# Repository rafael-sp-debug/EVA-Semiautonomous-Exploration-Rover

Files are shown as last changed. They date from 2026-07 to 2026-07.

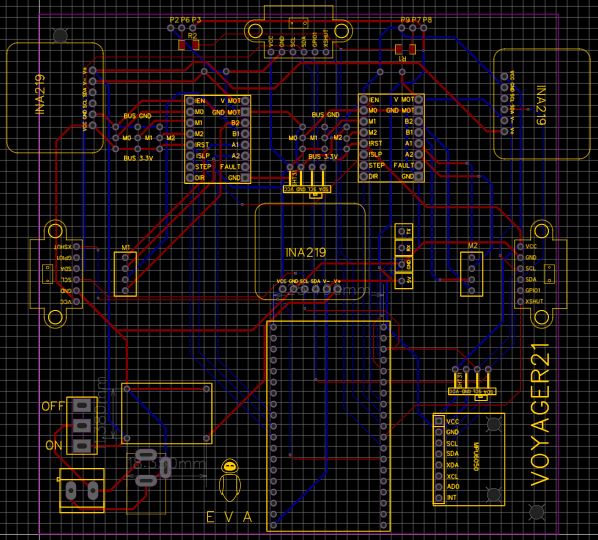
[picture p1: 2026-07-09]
Hardware/PCBs/ROVER_EVA.JPG

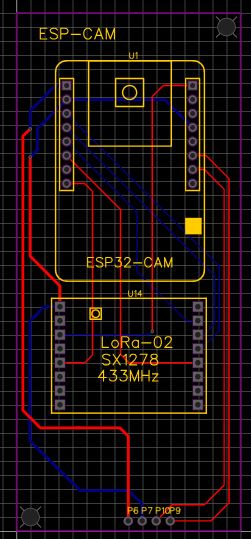
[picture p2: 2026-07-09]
Hardware/PCBs/CAM_EVA.JPG

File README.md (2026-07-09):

# EVA-Rover_2025 — Autonomous Exploration and Manual Control with LoRa

A complete hardware and software system that controls the differential rover **EVA** through an exploration cycle: autonomous navigation with obstacle avoidance, manual control, real-time telemetry transmission, and image capture. All operated from a remote ground station via long-range links.

The rover integrates sensor fusion for health monitoring (IMU, ToF, Voltage/Current), an **A*** path planner for grid navigation, and a **Computer Vision (YOLOv8 and OpenCV)** system at the base station for object and color detection. The entire system is orchestrated by an adaptive dynamic communication protocol over **LoRa**.

> Developed for the Space Technologies concentration at Tecnológico de Monterrey. 








---

## Demo

https://github.com/user-attachments/assets/1a435b37-e4af-4b8c-88f6-09a919b76a1f

| | |
|---|---|
| **Mission** | Explore the terrain manually or autonomously, avoid obstacles, capture images, and send real-time telemetry. |
| **Mechanical Design** | Modular PLA chassis < 20x20 cm, TPU tires for high traction, NEMA17 actuators. |
| **Sensors** | MPU6050 (IMU), VL53L0X x3 (ToF Distance), INA219 (Power), SHT31/AHT10 (Temp/Hum). |
| **Navigation** | A* Planner (Manhattan Heuristic) with reactive Evasion and Escape modes. |
| **Communications** | LoRa link (433MHz) with dynamic adaptation of SF and Bandwidth (Short/Mid/Long range). |
| **Computer Vision** | Base64 capture via ESP32-CAM; YOLOv8 (Faces/Rovers) and OpenCV (Colors) detection at the ground base. |

---

## How it Works

The system is divided into independent subsystems running on three main microcontrollers: an ESP32 and an ESP32-CAM on the rover, and an ESP32 at the ground station.

```text
                  [ ESP32-CAM (Payload) ]
                             │ Base64 Image Chunks
                             ▼
 ┌─────────────────────────────────────────────────────┐      LoRa (433MHz)       ┌───────────────────────┐
 │                      EVA ROVER                      │ ◄── (Commands / ACKs) ──►│    GROUND STATION     │
 │                                                     │ ◄───── (Telemetry) ─────►│                       │
 │  [ ESP32U Central ]                                 │                          │  [ ESP32U ]           │
 │     ├─ Navigation (MotorTask, A*)                   │                          │      │ (UART-USB)     │
 │     ├─ Telemetry (I2C: IMU, ToF, INA219, SHT31)     │                          │      ▼                │
 │     └─ Actuators (DRV8825 -> NEMA17)                │                          │  [ Computer (PC) ]    │
 └─────────────────────────────────────────────────────┘                          │  Web UI (WebSockets)  │
                                                                                  │  Digital Twin         │
                                                                                  │  Vision (YOLO/OpenCV) │
                                                                                  └───────────────────────┘
```
---
## Subsystems (Modules)

| Subsystem | Description | Key Components |
|---|---|---|
| **Communications** | Pseudo-full duplex bidirectional link. Dynamically adapts its Spreading Factor (SF7 to SF11) based on average RSSI to secure the link. | Ra-02 Modules (LoRa 433MHz), UART |
| **Sensors** | Collects 24 scaled sensory variables in a 65-byte CSV packet sent to the base. Manages visual rover states via a Neopixel matrix. | MPU6050, VL53L0X, INA219, AHT10 |
| **Navigation** | Discretizes the environment into 33 cm cells. Uses A* to plan routes towards targets (`GOAL X Y`). If a ToF sensor detects a blockage, it triggers bypass (evasion) or 180° turn (escape) modes. | ESP32U, DRV8825, NEMA17 |
| **Payload (Capture)** | Captures images, encodes them in Base64, and splits them into chunks (e.g., 64-200 bytes). Sends them with integrity checks, re-requesting lost parts. | ESP32-CAM, OV2640 Camera |
| **Ground Station** | Generates a WiFi Access Point. Deploys a Web Dashboard (HTML/JS/CSS) that graphs telemetry, draws the obstacle map, and sends commands via WebSockets. | Embedded Web Server, Python |

---

## Commands and Control

The system processes the following commands sent from the serial interface or the web dashboard to the rover:

| Command | Action | Command | Action |
|---|---|---|---|
| `W`, `S` | Move Forward / Backward one cell | `AUTO` / `STOPAUTO` | Starts / Stops autonomous navigation mode |
| `A`, `D` | Turn 90° Left / Right | `GOAL X Y` | Sets a target at X, Y coordinates |
| `IMAGE` | Capture and request an image | `REVERSE` | Returns the rover to the origin (0,0) |
| `START` / `STOP` | Start / Stop telemetry flow | `OBJ X Y` | Manually defines a logical obstacle on the map |
| `FORCE###` | Forces LoRa mode (`SHORT`, `MID`, `LONG`) | `CLEARALL` | Resets the map and robot position |

---

## Technical Approach

*   **Dynamic LoRa Adaptation:** To prevent packet loss over long distances, the station evaluates the average RSSI. If it drops below specific thresholds (-65 dBm, -95 dBm), the system automatically negotiates a mode change (increasing the Spreading Factor from SF7 to SF9 or SF11 and the preamble), sacrificing speed for robustness.
*   **Secure Image Transmission:** Since LoRa easily loses packets, images are encoded in Base64 and sent in small "Chunks". The station requests the pieces one by one, verifying their length and ASCII content. If a timeout or error occurs, it specifically re-requests that chunk.
*   **Safe Navigation:** All movement relies on a central non-blocking task (`motorTask()`). This prevents race conditions between telemetry and motor control, ensuring that odometry pose updates remain accurate.
*   **Digital Twin & Vision:** The project features a digital twin in Webots that replicates the real robot's movements in 3D using received telemetry. Additionally, images arriving at the PC go through YOLOv8 (trained on 10,000 augmented images) to detect faces and rovers, and OpenCV for color segmentation (Red, Blue, Green, Yellow).

---

## Installation and Materials

To replicate this project, you need to manufacture the custom PCBs and assemble the 3D design.

**Main Materials:**
*   4x 18650 Li-ion Batteries and MP1584 Regulator
*   2x NEMA17 Motors with DRV8825 drivers
*   2x ESP32-DevKitC-32U and 1x ESP32-CAM
*   2x Ra-02 LoRa Modules (433MHz)
*   PLA (Chassis) and TPU (Tires) filaments

*(All technical information, STL files, and detailed BOM can be found in the `/Hardware` folder of the repository).*

---

## Authors

*   Rafael Soto Padilla
*   José Eduardo Castellanos Avila
*   Nicolas De Bruijn Prieto
*   Diana Marisol Hernández Jiménez

## References

1. **Macenski, S., Foote, T., Gerkey, B., et al.** (2022). *Robot Operating System 2: Design, architecture, and uses in the wild*. Science Robotics, 7(66). [https://docs.ros.org/en/humble/](https://docs.ros.org/en/humble/)
2. **Jocher, G., Chaurasia, A., & Qiu, J.** (2023). *Ultralytics YOLOv8* (Version 8.0.0) [Computer software]. [https://github.com/ultralytics/ultralytics](https://github.com/ultralytics/ultralytics)
3. **Hart, P. E., Nilsson, N. J., & Raphael, B.** (1968). *A Formal Basis for the Heuristic Determination of Minimum Cost Paths*. IEEE Transactions on Systems Science and Cybernetics, 4(2), 100-107.
4. **Espressif Systems.** (2023). *ESP32 Series Datasheet*. [https://www.espressif.com/sites/default/files/documentation/esp32_datasheet_en.pdf](https://www.espressif.com/sites/default/files/documentation/esp32_datasheet_en.pdf)
5. **Semtech Corporation.** (2020). *LoRa Modulation Basics* (AN1200.22). [https://semtech.my.salesforce.com/sfc/p/E0000000JelG/a/2R0000001Rbr/6EfVZUorrpoKFfvaF_Fkpgp5kzjiNyiAbqcpqh9qSjE](https://semtech.my.salesforce.com/sfc/p/E0000000JelG/a/2R0000001Rbr/6EfVZUorrpoKFfvaF_Fkpgp5kzjiNyiAbqcpqh9qSjE)
6. **Bradski, G.** (2000). *The OpenCV Library*. Dr. Dobb's Journal of Software Tools. [https://opencv.org/](https://opencv.org/)

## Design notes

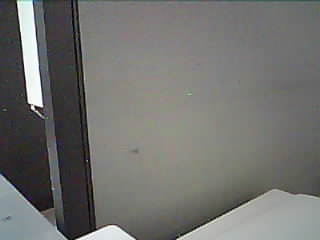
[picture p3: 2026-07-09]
Documentación/Evaluaciones/Cetec - CEDES.jpeg

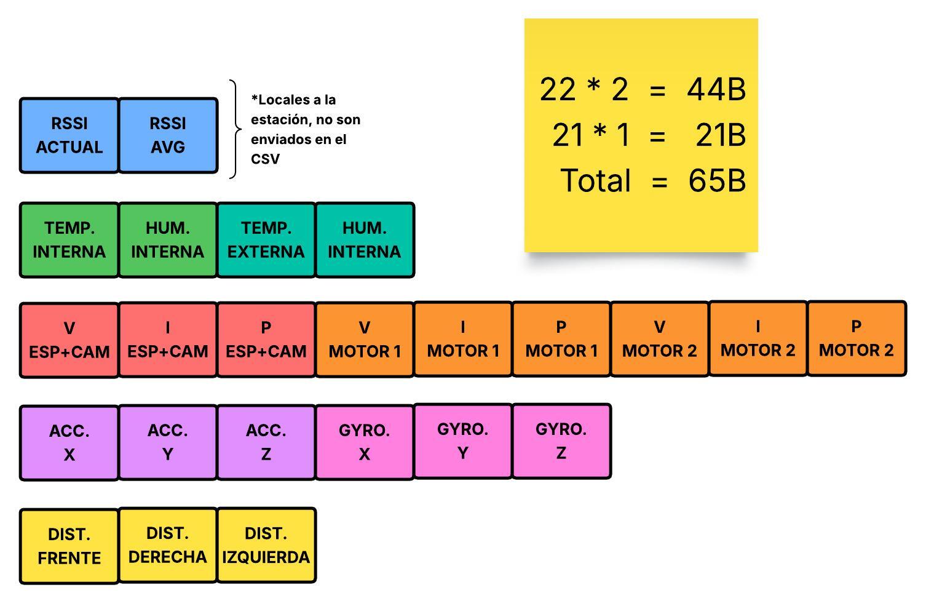
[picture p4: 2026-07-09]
Documentación/Diagramas/Estructura CSV.jpeg

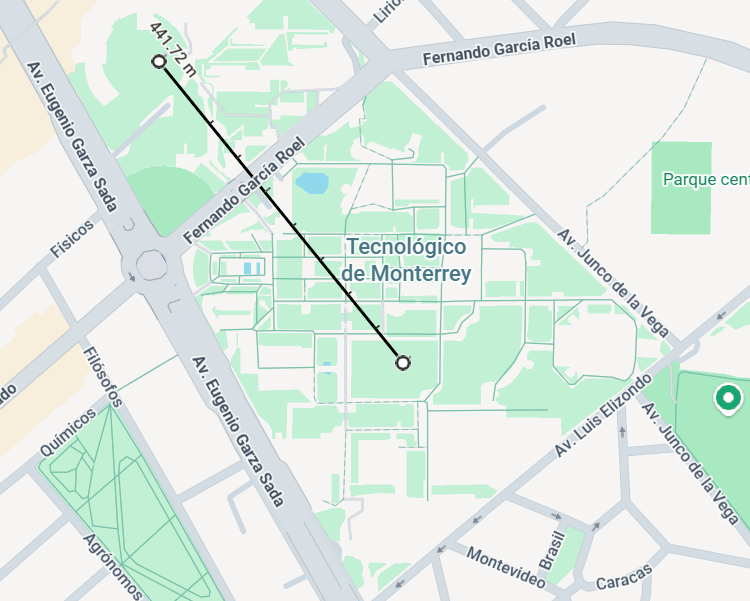
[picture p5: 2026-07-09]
Documentación/Evaluaciones/Distancia_BIBLIO - CEDES.png

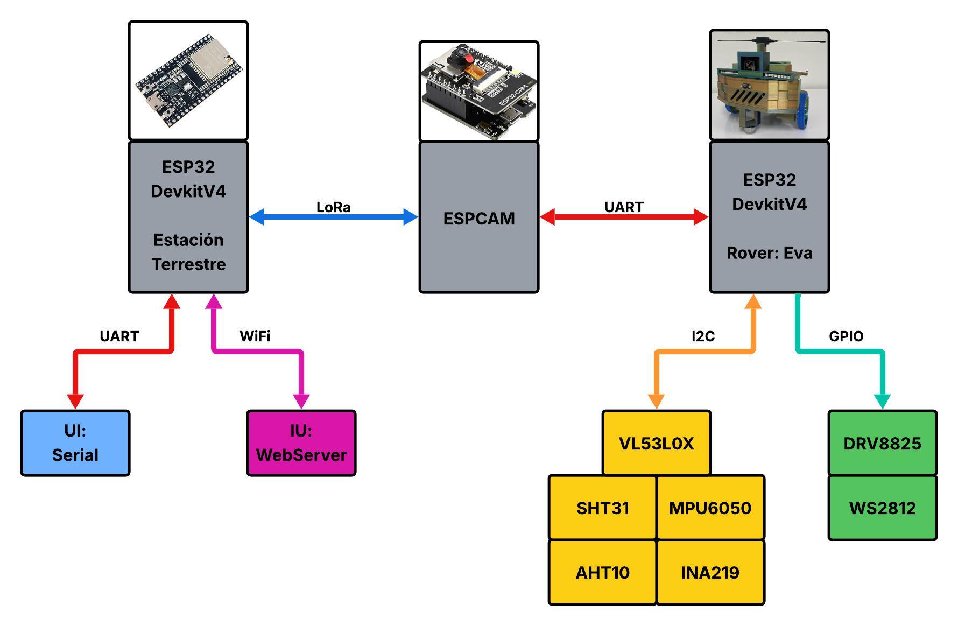
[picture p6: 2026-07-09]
Documentación/Diagramas/Protocolos Empleados.jpeg

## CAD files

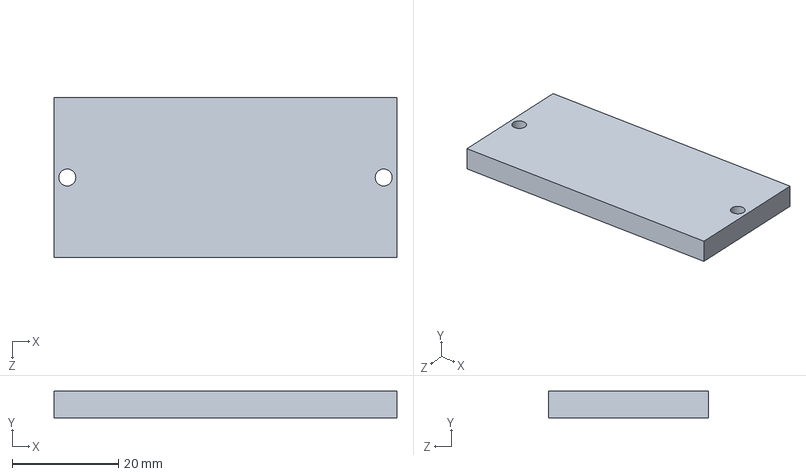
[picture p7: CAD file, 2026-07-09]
Hardware/Renders/Est./puerte de estacion.SLDPRT
64.5 x 5.00 x 30.0 mm

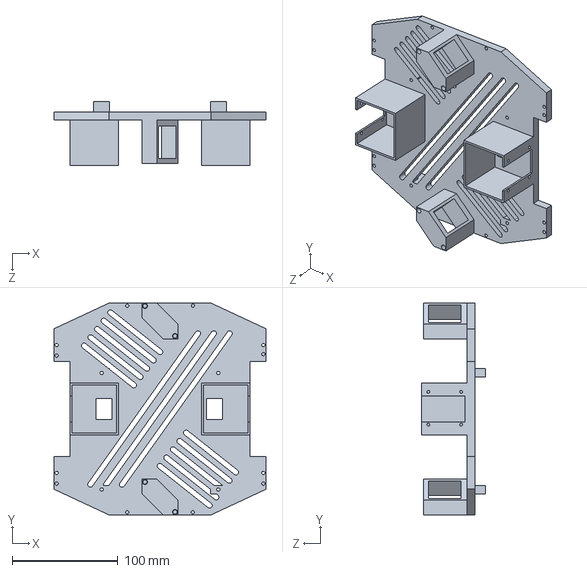
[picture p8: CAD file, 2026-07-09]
Hardware/Renders/Rov./chasiis.stp.SLDPRT
200.0 x 200.0 x 60.8 mm

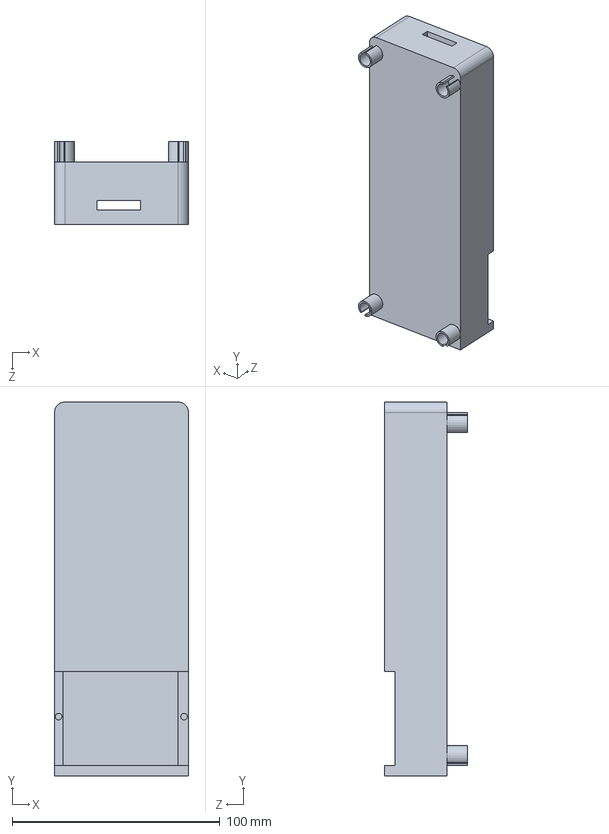
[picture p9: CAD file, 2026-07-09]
Hardware/Renders/Est./estacion.SLDPRT
64.5 x 180.0 x 40.0 mm

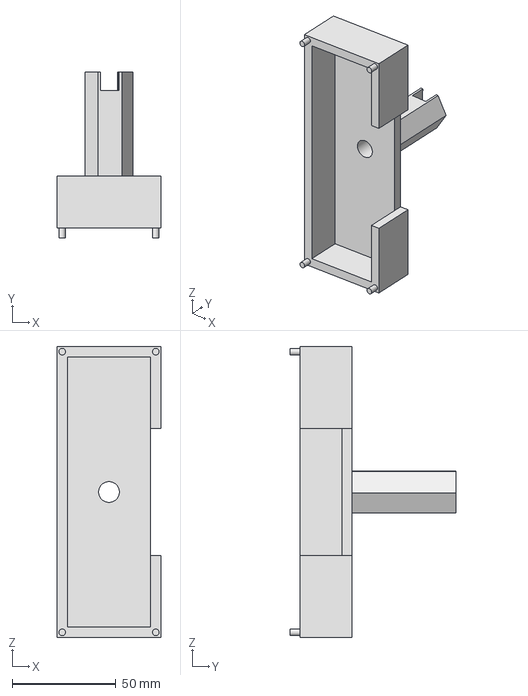
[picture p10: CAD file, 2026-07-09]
Hardware/Renders/Est./Caja_Antena[1].step
50.0 x 80.0 x 140.0 mm

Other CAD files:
Hardware/Renders/Rov./Aro_Rover.ipt
Hardware/Renders/Rov./Caja_Antena.ipt
Hardware/Renders/Rov./Caja_Bateria.ipt
Hardware/Renders/Rov./Caja_Camara.ipt
Hardware/Renders/Rov./Chasis.ipt
Hardware/Renders/Rov./Eva_Voyager21.iam
Hardware/Renders/Rov./Pared1_Chasis.ipt
Hardware/Renders/Rov./Pared2_Chasis.ipt
Hardware/Renders/Rov./Ruedas_Rover.ipt
Hardware/Renders/Rov./Techo_Chasis.ipt

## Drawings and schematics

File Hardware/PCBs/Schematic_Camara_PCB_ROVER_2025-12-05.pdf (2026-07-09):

LORA | ALIMENTACI N

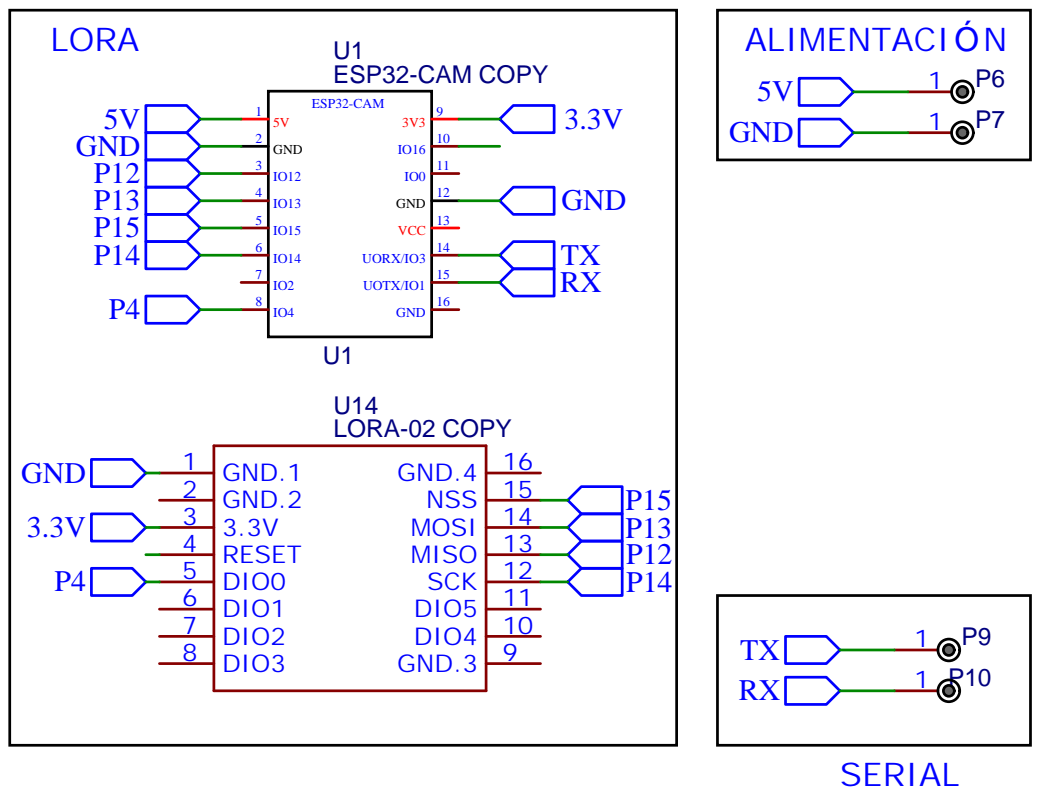
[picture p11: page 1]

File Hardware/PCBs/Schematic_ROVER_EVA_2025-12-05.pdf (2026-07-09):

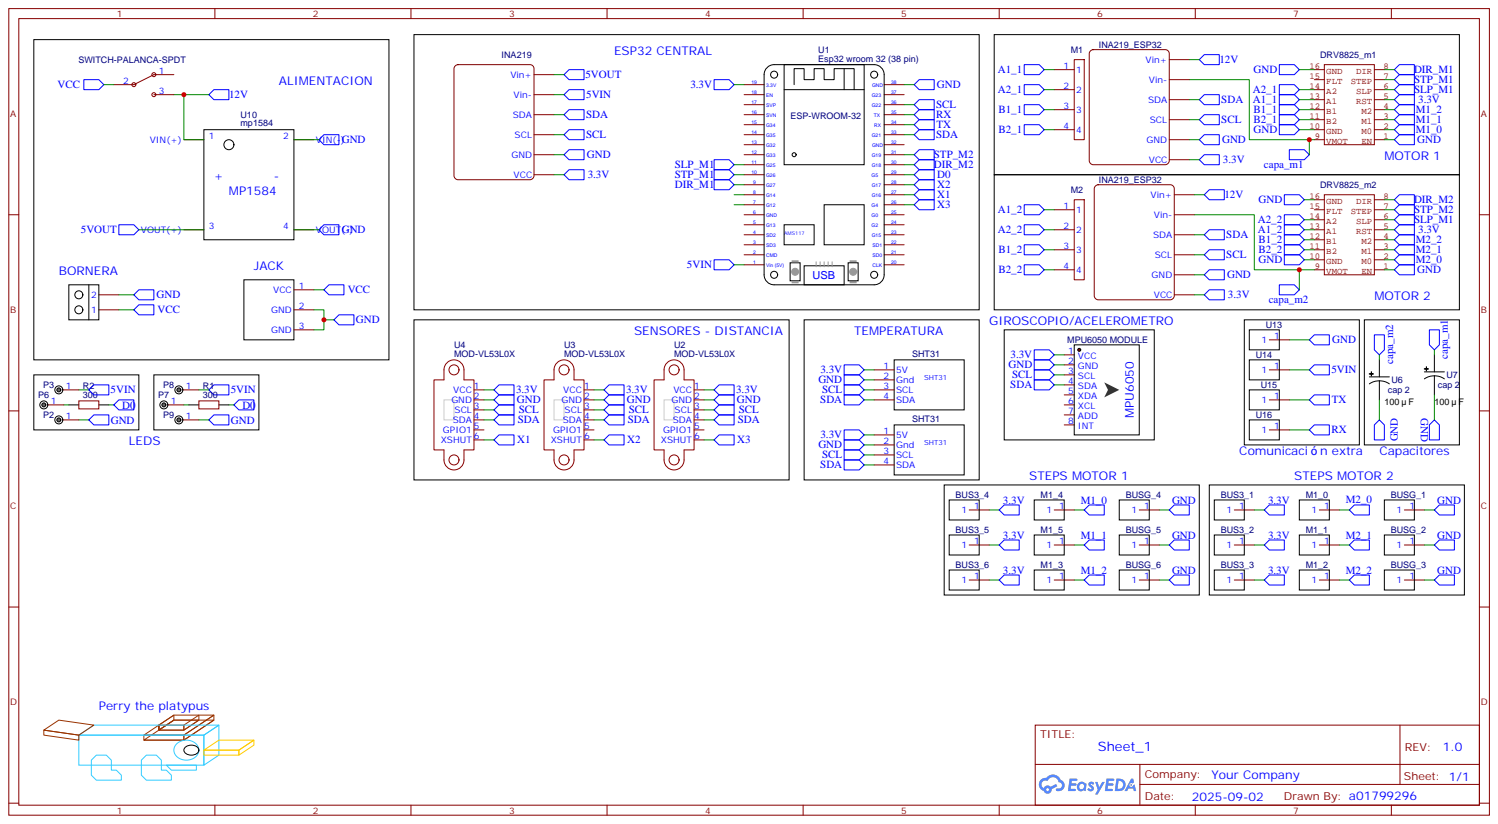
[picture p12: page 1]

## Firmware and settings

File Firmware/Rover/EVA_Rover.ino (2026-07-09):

//IMPORTACIONES//
#include <Wire.h>
#include <Arduino.h>
#include <Adafruit_INA219.h>
#include <Adafruit_SHT31.h>
#include <Adafruit_MPU6050.h>
#include <Adafruit_Sensor.h>
#include <Adafruit_AHTX0.h>
#include <VL53L0X.h>
#include <Adafruit_NeoPixel.h>
#include "esp_task_wdt.h" //wd

//DECLARACIONES//
VL53L0X sensor1; // Sensor de distancia 1
VL53L0X sensor2; // Sensor de distancia 2
VL53L0X sensor3; // Sensor de distancia 3
Adafruit_INA219 ina219_ESP(0x40); // Sensor de corriente ESP32
Adafruit_INA219 ina219_M1(0x41); // Sensor de corriente Motor 1
Adafruit_INA219 ina219_M2(0x45); // Sensor de corriente Motor 2
Adafruit_SHT31 sht31 = Adafruit_SHT31(); // Sensor temperatura y humedad SHT31
Adafruit_MPU6050 mpu; // Sensor inercial MPU6050
Adafruit_AHTX0 aht; // Sensor temperatura y humedad AHT10

#define DIR1_PIN 27 // Pin dirección motor 1
#define STEP1_PIN 26 // Pin paso motor 1
#define SLEEP_PIN 25 // Pin sleep motores
#define DIR2_PIN 18 // Pin dirección motor 2
#define STEP2_PIN 19 // Pin paso motor 2

#define XSHUT1 16 // Pin XSHUT sensor VL53L0X 1
#define XSHUT2 17 // Pin XSHUT sensor VL53L0X 2
#define XSHUT3 4 // Pin XSHUT sensor VL53L0X 3
#define RX_PIN 3 // Pin UART RX LoRa
#define TX_PIN 1 // Pin UART TX LoRa

#define LED_PIN 5 // Pin control LEDs NeoPixel
#define LED_COUNT 8 // Cantidad de LEDs NeoPixel
Adafruit_NeoPixel strip(LED_COUNT, LED_PIN, NEO_GRB + NEO_KHZ800); // Tira de LEDs NeoPixel

int stepsPerRev = 3840; // Pasos por revolución del motor
#define STEP_DELAY_US 70 // Velocidad de paso en microsegundos
#define WDT_TIMEOUT 10 // Timeout watchdog en segundos

bool ledBreathing = false; // Modo LED respiración activo
bool ledFlashing = false; // Modo LED parpadeo activo
bool ledRainbow = false; // Modo LED arcoíris activo
bool ledDot = false; // Modo LED punto activo
bool ledIdle = true; // Modo LED inactivo activo
bool ledCam = false; // Modo LED cámara activo
bool ledObstacle = false; // Modo LED obstáculo rojo activo

bool shtPresent = false; // Sensor SHT31 presente
bool ahtPresent = false; // Sensor AHT10 presente
bool inaESP_Present = false; // Sensor INA219 ESP32 presente
bool inaM1_Present = false; // Sensor INA219 Motor 1 presente
bool inaM2_Present = false; // Sensor INA219 Motor 2 presente
bool mpuPresent = false; // Sensor MPU6050 presente

unsigned long previousMillis = 0; // Tiempo anterior para intervalo CSV
unsigned long previousPing = 0; // Tiempo anterior para intervalo PING
float intervalSec = 1.5; // Intervalo en segundos para envío CSV
unsigned long interval = intervalSec * 1000; // Intervalo convertido a milisegundos
unsigned long pinginterval = 30000; // Intervalo convertido a milisegundos
bool sendCSV = false; // Bandera para controlar envío CSV
bool sendingImg = false; // Bandera para indicar si imagen se está enviando
bool sendTelemetry = true; // Bandera para alternar entre telemetría y grid

#define CSV_BUFFER_SIZE 96 // Tamaño del buffer CSV
char csvBuffer[CSV_BUFFER_SIZE]; // Buffer para datos CSV

enum MotorCommand {
  MOTOR_IDLE, // Motor inactivo
  MOTOR_BOTH_CW, // Ambos motores sentido horario
  MOTOR_BOTH_CCW, // Ambos motores sentido antihorario
  MOTOR_OPPOSITE_A, // Motores opuestos giro izquierda
  MOTOR_OPPOSITE_D // Motores opuestos giro derecha
};

volatile MotorCommand currentCommand = MOTOR_IDLE; // Comando actual del motor
TaskHandle_t watchdogTaskHandle = NULL; // Handle de tarea watchdog

const int GRID_W = 10; // Ancho del grid en celdas
const int GRID_H = 10; // Alto del grid en celdas
uint8_t occGrid[GRID_W][GRID_H]; // Grid de ocupación: 0 libre, 1 obstáculo

const float WHEEL_RADIUS = 0.04f; // Radio de rueda en metros
const float WHEEL_CIRC = 2.0 * 3.14159265358979323846f * WHEEL_RADIUS; // Circunferencia de rueda en metros
const float CELL_SIZE_M = 0.365f; // Tamaño de celda en metros (valor por defecto)

volatile int posX = 0; // Posición X actual en celdas
volatile int posY = 0; // Posición Y actual en celdas
volatile int heading = 0; // Orientación: 0=Norte, 1=Este, 2=Sur, 3=Oeste

volatile int goalX = 0; // Coordenada X del objetivo en celdas
volatile int goalY = 0; // Coordenada Y del objetivo en celdas
volatile bool haveGoal = false; // Bandera de objetivo definido

volatile bool autoMode = false; // Bandera modo autónomo activo
volatile bool autoPaused = false; // Bandera modo autónomo pausado
volatile bool movingFlag = false; // Bandera de movimiento en ejecución
volatile bool obstacleFlag = false; // Bandera de obstáculo detectado
volatile bool evasionMode = false; // Bandera de modo evasión
volatile int evasionCellsCount = 0; // Contador de celdas avanzadas en modo evasión
const int EVASION_CELLS_MIN = 2; // Mínimo de celdas a avanzar en modo evasión antes de recalcular path

struct Cell { int x; int y; }; // Estructura de celda del grid
Cell pathCells[GRID_W * GRID_H]; // Array de celdas del camino
int pathLen = 0; // Longitud del camino
int pathIndex = 0; // Índice actual en el camino

volatile int stepsPerCell = 0; // Declaración de stepsPercell
const int turnSteps = 3740; // Pasos para giro de 90 grados

volatile int stepsToDo = 0; // Pasos objetivo para motorTask
volatile int stepsDone = 0; // Pasos completados por motorTask
volatile MotorCommand activeMotorCommand = MOTOR_IDLE; // Comando de motor en ejecución
volatile int desiredHeadingAfterTurn = -1; // Dirección deseada después del giro (-1 = no hay giro pendiente)

unsigned long lastAutoTick = 0; // Último tick del modo autónomo
const unsigned long AUTO_STEP_DELAY_MS = 50; // Retardo entre pasos autónomos en ms

const int MAXN = GRID_W * GRID_H; // Tamaño máximo para arrays A*
static bool astar_closed[MAXN]; // Array de nodos cerrados A*
static int astar_gscore[MAXN]; // Array de puntuación G A*
static int astar_fscore[MAXN]; // Array de puntuación F A*
static int astar_came_from[MAXN]; // Array de nodos previos A*
static int astar_openList[MAXN]; // Lista abierta A*
static int astar_revPath[MAXN]; // Camino reverso A*

//Declaración de funciones
void planPathAstar();
bool astar(int sx, int sy, int gx, int gy, Cell *outPath, int &outLen);
int heuristic(int ax, int ay, int bx, int by);
void occupancyMarkFromSensorReadings();
void markObstacleCellFromSensor(int sensorIndex, int distance_mm);
void executeNextStepFromPathNonBlocking();
void rotateToDirNonBlocking(int desiredDir);
void queueForwardOneCellNonBlocking();
void queueBackwardOneCellNonBlocking();
void calculateStepsPerCell();
void updatePoseAfterForward();
void clearMapKeepPose();
void clearAllResetPose();
void appendNavBinary();
bool checkObstacleInFront();
void executeAutonomousMode();

// Inicialización del sistema
void setup() {
  Serial.begin(115200);
  Serial.setDebugOutput(false);

  const esp_task_wdt_config_t wdt_config = {
        .timeout_ms = WDT_TIMEOUT * 1000,
        .idle_core_mask = (1 << 0) | (1 << 1),
        .trigger_panic = true
  };
  esp_task_wdt_init(&wdt_config);

  esp_task_wdt_add(NULL);
  Serial.println("WATCHDOG_LOOP_ENABLED");

  xTaskCreatePinnedToCore(
    watchdogTask,
   "watchdogTask",
    4096,
    NULL,
    1,
    &watchdogTaskHandle,
    0
  );

  strip.begin();
  strip.show();

  pinMode(DIR2_PIN, OUTPUT);
  pinMode(STEP2_PIN, OUTPUT);
  pinMode(SLEEP_PIN, OUTPUT);
  pinMode(DIR1_PIN, OUTPUT);
  pinMode(STEP1_PIN, OUTPUT);

  digitalWrite(SLEEP_PIN, LOW);
  
  xTaskCreatePinnedToCore(
    motorTask,
    "MotorTask",
    4096,
    NULL,
    1,
    NULL,
    1
  );

  xTaskCreatePinnedToCore(
    ledTask,
    "LED Task",
    2048,
    NULL,
    1,
    NULL,
    1
  );

  pinMode(XSHUT1, OUTPUT);
  pinMode(XSHUT2, OUTPUT);
  pinMode(XSHUT3, OUTPUT);

  digitalWrite(XSHUT1, LOW);
  digitalWrite(XSHUT2, LOW);
  digitalWrite(XSHUT3, LOW);
  delay(1000);

  Wire.begin();
  delay(200);

  digitalWrite(XSHUT1, HIGH);
  delay(150);
  sensor1.init(true);
  sensor1.setAddress(0x30);

  digitalWrite(XSHUT2, HIGH);
  delay(150);
  sensor2.init(true);
  sensor2.setAddress(0x31);

  digitalWrite(XSHUT3, HIGH);
  delay(150);
  sensor3.init(true);
  sensor3.setAddress(0x32);
  
  delay(100);

  sensor1.startContinuous();
  sensor2.startContinuous();
  sensor3.startContinuous();
  
  inaESP_Present = ina219_ESP.begin();
  if (!inaESP_Present) Serial.println("INA219_ESP NOT FOUND");

  inaM1_Present = ina219_M1.begin();
  if (!inaM1_Present) Serial.println("INA219_M1 NOT FOUND");

  inaM2_Present = ina219_M2.begin();
  if (!inaM2_Present) Serial.println("INA219_M2 NOT FOUND");

  shtPresent = sht31.begin(0x44);
  if (!shtPresent) Serial.println("SHT31 NOT FOUND");

  ahtPresent = aht.begin();
  if (!ahtPresent) Serial.println("AHT10 NOT FOUND");

  mpuPresent = mpu.begin();
  if (!mpuPresent) Serial.println("MPU6050 NOT FOUND");
  else {
      mpu.setAccelerometerRange(MPU6050_RANGE_8_G);
      mpu.setGyroRange(MPU6050_RANGE_500_DEG);
      mpu.setFilterBandwidth(MPU6050_BAND_21_HZ);
  }
  for (int i=0;i<GRID_W;i++) for (int j=0;j<GRID_H;j++) occGrid[i][j]=0;
  calculateStepsPerCell();
}

// Bucle principal
void loop() {
  unsigned long currentMillis = millis();

  esp_task_wdt_reset();

  if (sendCSV && currentMillis - previousMillis >= interval) {
    previousMillis = currentMillis;
    if (sendTelemetry) {
      getAllSensorsCSV();
      Serial.print(csvBuffer);
      Serial.println();
    } else {
      sendGridPacket();
    }
    sendTelemetry = !sendTelemetry;
  }

  else if (!sendCSV && !sendingImg && currentMillis - previousPing >= pinginterval) {
    previousPing = currentMillis;
    Serial.println("PING");
  }

  if (Serial.available()) {
    String cmd = Serial.readStringUntil('\n');
    cmd.trim();

    if (cmd.equalsIgnoreCase("IMGSTART")) {
      sendingImg = true;
      previousPing = millis();
      ledFlashing = true;
      ledBreathing = ledRainbow = ledDot = ledCam = false;
    }
    else if (cmd.equalsIgnoreCase("IMGDONE")) {
      sendingImg = false;
      ledFlashing = false;
    }
    else if (cmd.equalsIgnoreCase("GO")) {
      if (sendCSV) {
        Serial.println("CSV_ALREADY_STARTED");
      } else {
        sendCSV = true;
        Serial.println("CSV_SENDING_STARTED");
        ledBreathing = true;
        ledFlashing = ledRainbow = ledDot = ledCam = false;
      }
    }
    else if (cmd.equalsIgnoreCase("STP") || cmd.equalsIgnoreCase(".STOP")) {
      if (!sendCSV) {
        Serial.println("CSV_ALREADY_STOPPED");
      } else {
        sendCSV = false;
        ledBreathing = false;
        Serial.println("CSV_SENDING_STOPPED");
      }
    }
    else if (cmd.equalsIgnoreCase("RES")) {
      Serial.println("RE_EVA");
      delay(200);
      ESP.restart();
    }
    else if (cmd.startsWith("INT")) {
      float newIntervalSec = cmd.substring(3).toFloat();
      intervalSec = newIntervalSec;
      interval = (unsigned long)(intervalSec * 1000);
      Serial.println("CSV_INT" + String(intervalSec, 2));
    }
    else if (cmd.startsWith("SET")) {
      int newSteps = cmd.substring(3).toInt();
      if (newSteps > 0) {
        stepsPerRev = newSteps;
        // NO recalcular stepsPerCell aquí - el usuario puede cambiarlo manualmente
        Serial.println("NEMA_" + String(stepsPerRev));
      } else {
        Serial.println("ERROR_INVALID_STEPS");
      }
    } 
    else if (cmd.equalsIgnoreCase("W")) {
      if (autoMode && !autoPaused) {
        Serial.println("CURRENT_AUTONOMOUS_MODE");
      } else if (checkObstacleInFront()) {
        Serial.println("OBJECT_BLOCKING_FRONT");
      } else if (!movingFlag) {
        // Usar stepsPerCell directamente
        digitalWrite(DIR1_PIN, LOW);
        digitalWrite(DIR2_PIN, LOW);
        stepsToDo = stepsPerCell;
        stepsDone = 0;
        activeMotorCommand = MOTOR_BOTH_CW;
        movingFlag = true;
      }
    }
    else if (cmd.equalsIgnoreCase("S")) {
      if (autoMode && !autoPaused) {
        Serial.println("CURRENT_AUTONOMOUS_MODE");
      } else if (!movingFlag) {
        // Usar stepsPerCell directamente
        digitalWrite(DIR1_PIN, HIGH);
        digitalWrite(DIR2_PIN, HIGH);
        stepsToDo = stepsPerCell;
        stepsDone = 0;
        activeMotorCommand = MOTOR_BOTH_CCW;
        movingFlag = true;
      }
    }
    else if (cmd.equalsIgnoreCase(".NOSTEP")) {
      calculateStepsPerCell();
      Serial.println("STEPS_PER_CELL_RESET_TO_DEFAULT");
    }
    else if (cmd.equalsIgnoreCase("A")) {
      if (autoMode && !autoPaused) {
        Serial.println("CURRENT_AUTONOMOUS_MODE");
      } else {
        currentCommand = MOTOR_OPPOSITE_A;
      }
    }
    else if (cmd.equalsIgnoreCase("D")) {
      if (autoMode && !autoPaused) {
        Serial.println("CURRENT_AUTONOMOUS_MODE");
      } else {
        currentCommand = MOTOR_OPPOSITE_D;
      }
    }

    else if (cmd.startsWith("GOAL") || cmd.startsWith(".GOAL")) {
      int offset = cmd.startsWith(".GOAL") ? 5 : 4;
      String params = cmd.substring(offset);
      params.trim();
      int commaIndex = params.indexOf(',');
      if (commaIndex > 0) {
        String xStr = params.substring(0, commaIndex);
        String yStr = params.substring(commaIndex + 1);
        xStr.trim();
        yStr.trim();
        int gx = xStr.toInt();
        int gy = yStr.toInt();
        if (gx >= 0 && gx < GRID_W && gy >= 0 && gy < GRID_H) {
          goalX = gx;
          goalY = gy;
          haveGoal = true;
          Serial.println("GOAL_SET " + String(gx) + "," + String(gy));
        } else {
          Serial.println("ERROR_GOAL_OUT_OF_BOUNDS");
        }
      } else {
        Serial.println("ERROR_GOAL_FORMAT");
      }
    }
    else if (cmd.startsWith("OBJ") || cmd.startsWith(".OBJ")) {
      int offset = cmd.startsWith(".OBJ") ? 4 : 3;
      String params = cmd.substring(offset);
      params.trim();
      int commaIndex = params.indexOf(',');
      int spaceIndex = params.indexOf(' ');
      int separatorIndex = (commaIndex > 0) ? commaIndex : spaceIndex;
      
      if (separatorIndex > 0) {
        String xStr = params.substring(0, separatorIndex);
        String yStr = params.substring(separatorIndex + 1);
        xStr.trim();
        yStr.trim();
        int objX = xStr.toInt();
        int objY = yStr.toInt();
        if (objX >= 0 && objX < GRID_W && objY >= 0 && objY < GRID_H) {
          occGrid[objX][objY] = 1;
          Serial.println("OBJ_SET");
          if (autoMode && pathLen > 0) {
            pathIndex = 0;
            pathLen = 0;
            planPathAstar();
          }
        } else {
          Serial.println("ERROR_OBJ_OUT_OF_BOUNDS");
        }
      } else {
        Serial.println("ERROR_OBJ_FORMAT");
      }
    }
    else if (cmd.equalsIgnoreCase(".AUTO") || cmd.equalsIgnoreCase("AUTO")) {
      if (!haveGoal) {
        Serial.println("NO_GOAL_DEFINED");
      } else {
        pathLen = 0;
        pathIndex = 0;
        movingFlag = false;
        stepsToDo = 0;
        stepsDone = 0;
        activeMotorCommand = MOTOR_IDLE;
        desiredHeadingAfterTurn = -1;
        evasionMode = false;
        evasionCellsCount = 0;
        autoMode = true;
        autoPaused = false;
        lastAutoTick = millis();
        Serial.println("AUTO_STARTED");
      }
    }
    else if (cmd.equalsIgnoreCase("STOPAUTO") || cmd.equalsIgnoreCase(".STOPAUTO")) {
      autoPaused = true;
      autoMode = false;
      Serial.println("AUTO_STOPPED");
    }
    else if (cmd.equalsIgnoreCase("PAUSE") || cmd.equalsIgnoreCase(".PAUSE")){
      if (autoMode && !autoPaused) {
        autoPaused = true;
        Serial.println("AUTO_PAUSED");
      } else if (!autoMode) {
        Serial.println("AUTO_NOT_ACTIVE");
      } else {
        Serial.println("AUTO_ALREADY_PAUSED");
      }
    }
    else if (cmd.equalsIgnoreCase("RESUME") || cmd.equalsIgnoreCase(".RESUME")) {
      if (autoMode && autoPaused) {
        autoPaused = false;
        lastAutoTick = millis();
        // Recalcular ruta desde la posición actual
        pathIndex = 0;
        pathLen = 0;
        planPathAstar();
        Serial.println("AUTO_RESUMED");
      } else if (!autoMode) {
        Serial.println("AUTO_NOT_ACTIVE");
      } else {
        Serial.println("AUTO_NOT_PAUSED");
      }
    }
    else if (cmd.equalsIgnoreCase("REVERSE") || cmd.equalsIgnoreCase(".REVERSE")) {
      goalX = 0;
      goalY = 0;
      haveGoal = true;
      Serial.println("REVERSE_GOAL_SET");
    }
    else if (cmd.equalsIgnoreCase("CLEAR") || cmd.equalsIgnoreCase(".CLEAR")) {
      clearMapKeepPose();
      Serial.println("MAP_CLEARED");
    }
    else if (cmd.equalsIgnoreCase("CLEARALL") || cmd.equalsIgnoreCase(".CLEARALL")) {
      clearAllResetPose();
      Serial.println("MAP_CLEARED_AND_RESET");
    }
    else if (cmd.equalsIgnoreCase("FCAM")) {
      ledCam = true;
      ledBreathing = ledFlashing = ledRainbow = ledDot = false;
    }
    else if (cmd.equalsIgnoreCase("PARTY")) {
      ledRainbow = true;
      ledBreathing = ledFlashing =  ledDot = ledCam = false;
    }
  }
  if (autoMode && !autoPaused) {
    executeAutonomousMode(); // Llamar a función de modo autónomo
  }

  delay(2);
}

String getAllSensorsCSV() { //Función para obtener la info de los sensores en CSV
    sensors_event_t a, g, temp;
    mpu.getEvent(&a, &g, &temp);
    
    int16_t sht_temp_i = 0; // Temperatura SHT31 en centésimas
    int16_t sht_hum_i  = 0; // Humedad SHT31 en centésimas

    if (shtPresent) {
        float t = sht31.readTemperature();
        float h = sht31.readHumidity();
        if (!isnan(t) && !isnan(h)) {
            sht_temp_i = (int16_t)(t * 100);
            sht_hum_i  = (int16_t)(h * 100);
        } else {
            shtPresent = false;
        }
    }
    if (!shtPresent) shtPresent = tryBeginSHT();

    int16_t int_temp_i = 0; // Temperatura AHT10 en centésimas
    int16_t int_hum_i  = 0; // Humedad AHT10 en centésimas

    if (ahtPresent) {
        sensors_event_t ah, at;
        aht.getEvent(&ah, &at);
        if (!isnan(at.temperature)) {
            int_temp_i = (int16_t)(at.temperature * 100);
            int_hum_i  = (int16_t)(ah.relative_humidity * 100);
        } else {
            ahtPresent = false;
        }
    }
    if (!ahtPresent) ahtPresent = tryBeginAHT();

    int16_t espBusV_i = 0; // Voltaje bus ESP32 en centésimas
    int16_t espCurrent_i = 0; // Corriente ESP32 en décimas de mA
    int16_t espPower_i = 0; // Potencia ESP32 en mW

    if (inaESP_Present) {
        float v = ina219_ESP.getBusVoltage_V();
        if (!isnan(v)) {
            espBusV_i   = (int16_t)(v * 100);
            espCurrent_i = (int16_t)(ina219_ESP.getCurrent_mA() * 10);
            espPower_i   = (int16_t)(ina219_ESP.getPower_mW());
        } else {
            inaESP_Present = false;
        }
    }
    if (!inaESP_Present) inaESP_Present = tryBeginINA(ina219_ESP);

    int16_t m1BusV_i = 0; // Voltaje bus Motor 1 en centésimas
    int16_t m1Current_i = 0; // Corriente Motor 1 en décimas de mA
    int16_t m1Power_i = 0; // Potencia Motor 1 en mW

    if (inaM1_Present) {
        float v = ina219_M1.getBusVoltage_V();
        if (!isnan(v)) {
            m1BusV_i = (int16_t)(v * 100);
            m1Current_i = (int16_t)(ina219_M1.getCurrent_mA() * 10);
            m1Power_i = (int16_t)(ina219_M1.getPower_mW());
        } else {
            inaM1_Present = false;
        }
    }
    if (!inaM1_Present) inaM1_Present = tryBeginINA(ina219_M1);

    int16_t m2BusV_i = 0; // Voltaje bus Motor 2 en centésimas
    int16_t m2Current_i = 0; // Corriente Motor 2 en décimas de mA
    int16_t m2Power_i = 0; // Potencia Motor 2 en mW

    if (inaM2_Present) {
        float v = ina219_M2.getBusVoltage_V();
        if (!isnan(v)) {
            m2BusV_i = (int16_t)(v * 100);
            m2Current_i = (int16_t)(ina219_M2.getCurrent_mA() * 10);
            m2Power_i = (int16_t)(ina219_M2.getPower_mW());
        } else {
            inaM2_Present = false;
        }
    }
    if (!inaM2_Present) inaM2_Present = tryBeginINA(ina219_M2);

    int16_t accX_i = a.acceleration.x * 100; // Aceleración X en centésimas
    int16_t accY_i = a.acceleration.y * 100; // Aceleración Y en centésimas
    int16_t accZ_i = a.acceleration.z * 100; // Aceleración Z en centésimas
    int16_t gyroX_i = g.gyro.x * 100; // Giroscopio X en centésimas
    int16_t gyroY_i = g.gyro.y * 100; // Giroscopio Y en centésimas
    int16_t gyroZ_i = g.gyro.z * 100; // Giroscopio Z en centésimas

    int16_t dist1 = sensor1.readRangeContinuousMillimeters(); // Distancia sensor 1 en mm
    int16_t dist2 = sensor2.readRangeContinuousMillimeters(); // Distancia sensor 2 en mm
    int16_t dist3 = sensor3.readRangeContinuousMillimeters(); // Distancia sensor 3 en mm

    snprintf(csvBuffer, CSV_BUFFER_SIZE,
        "%d,%d,%d,%d,"
        "%d,%d,%d,"
        "%d,%d,%d,"
        "%d,%d,%d,"
        "%d,%d,%d,%d,%d,%d,"
        "%d,%d,%d",
        sht_temp_i, sht_hum_i, int_temp_i, int_hum_i,
        espBusV_i, espCurrent_i, espPower_i,
        m1BusV_i, m1Current_i, m1Power_i,
        m2BusV_i, m2Current_i, m2Power_i,
        accX_i, accY_i, accZ_i, gyroX_i, gyroY_i, gyroZ_i,
        dist1, dist2, dist3
    );

    return String(csvBuffer);
}
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

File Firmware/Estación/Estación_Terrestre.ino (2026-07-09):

#include <SPI.h>
#include <LoRa.h>
#include <WiFi.h>
#include <WebSocketsServer.h>
#include <WebServer.h>
#include "esp_task_wdt.h"
#include <LittleFS.h>
#define LORA_FREQ 433E6
#define LORA_SS   5    // CS
#define LORA_DIO0 25   // DIO0
#define WDT_TIMEOUT 10   // seconds

//////////////////////////////////////////////////////////////////////////////////////////////////// HTML embebido
const char index_html[] PROGMEM = R"rawliteral(

)rawliteral";

//////////////////////////////////////////////////////////////////////////////////////////////////// JS embebido
const char main_js[] PROGMEM = R"rawliteral(

)rawliteral";

const char* apSSID = "EVA_Dashboard";
const char* apPassword = "VOYAGER21"; //min 8 caracteres

WebServer server(80);
WebSocketsServer webSocket = WebSocketsServer(81);

uint8_t controllerClient = 255; // 255 = no hay controlador aún

String imgBuffer = "";
String webImage = "";

TaskHandle_t watchdogTaskHandle = NULL;

int expectedChunks = 0;
int receivedChunks = 0;
bool receivingImage = false;

String msgToSend = "";                    // Fila de mensaje de monitor serial
bool msgQueued = false;

unsigned long retryInterval = 100;        // Default LoRa SHORT: ms entre intervalos de envío
unsigned long ackTimeout = 500;           // Default LoRa MID: 500ms espera en reintento
unsigned long chunkTimeout = 1500;        // Default LoRa MID: 1.5 segundos para reenviar solicitud de chunk

unsigned long msgStartTime = 0;           // Cuando el mensaje fue enviado
unsigned long lastSendAttempt = 0;        // Cuando el mensaje se intentó enviar
unsigned long lastChunkRequestTime = 0;   // Cuando el chunk se solicitó por última vez

int expectedLength = 200;
float csvInt = 1.5;
int nemaStep = 3740;
String currGoal = "";

// Estados LoRa
enum LoRaRange { SHORT, MID, LONG };
LoRaRange currentRange = SHORT;  // Iniciar SHORT

// RSSI Umbral
const int shortToMid = -65;   // SHORT -> MID
const int midToShort  = -45;  // MID -> SHORT
const int midToLong   = -110; // MID -> LONG
const int longToMid   = -90;  // LONG -> MID

// Promedio RSSI
const int rssiSampleCount = 4;    // Muestras en promediado
int rssiSamples[rssiSampleCount] = {0};
int sampleIndex = 0;
int sampleTotal = 0;
int sampleFilled = 0;

void setup() {
  Serial.begin(115200);
  while (!Serial);

  if (!LittleFS.begin()) {
    Serial.println("ERR_LittleFS");
  }
  
  const esp_task_wdt_config_t wdt_config = {
        .timeout_ms = WDT_TIMEOUT * 1000,
        .idle_core_mask = (1 << 0) | (1 << 1),
        .trigger_panic = true
  };
  esp_task_wdt_init(&wdt_config);

  esp_task_wdt_add(NULL);
  Serial.println("WATCHDOG_LOOP_ENABLED");

  xTaskCreatePinnedToCore(
    watchdogTask,           // task function
    "watchdogTask",         // name
    4096,                   // stack size
    NULL,                   // parameter
    1,                      // priority
    &watchdogTaskHandle,    // task handle
    0                       // core 0 (low priority)
  );

  // Start AP
  esp_log_level_set("wifi", ESP_LOG_NONE);
  WiFi.softAP(apSSID, apPassword);
  IPAddress IP = WiFi.softAPIP();
  Serial.print("\nConectar a Dashboard: http://");
  Serial.println(IP);

  // Serve HTML
  server.on("/", HTTP_GET, []() {
    server.send_P(200, "text/html", index_html);
  });

  // Serve JS
  server.on("/main.js", HTTP_GET, []() {
    server.send_P(200, "application/javascript", main_js);
  });

  server.on("/chart.umd.min.js", HTTP_GET, []() {
    File file = LittleFS.open("/chart.umd.min.js", "r");
    if (!file) {
      server.send(404, "text/plain", "chart.umd.min.js not found");
      return;
    }
    server.streamFile(file, "application/javascript");
    file.close();
  });


  server.begin();

  // WebSocket - Servidor
  webSocket.begin();
  webSocket.onEvent(onWebSocketEvent);

  SPI.begin();

  LoRa.setPins(LORA_SS, -1, LORA_DIO0);

  if (!LoRa.begin(LORA_FREQ)) {
    Serial.println("AP_ERR_LoRa_FAILED");
    while (true);
  }

  LoRa.setTxPower(20);
  LoRa.setSpreadingFactor(7); // Spreading Factor
  LoRa.setSignalBandwidth(250E3); // BW
  LoRa.setCodingRate4(5); // Coding Rate
  LoRa.setSyncWord(0x88); // Sync word
  LoRa.setPreambleLength(6); // Preamble:
  LoRa.enableCrc(); // CRC

  Serial.println("Voyager21: Comunicación LoRa Habillitada");
  Serial.println("'.COMLIST' para Lista de Comandos Disponibles");
}

void loop() {
  unsigned long now = millis();

  esp_task_wdt_reset();

  webSocket.loop();
  server.handleClient();

  // Recepción LORA
  int packetSize = LoRa.parsePacket();
  if (packetSize) {
    String received = "";
    while (LoRa.available()) received += (char)LoRa.read();
    received.trim();

    // Filtrar basura
    bool valid = true;
    for (unsigned int i = 0; i < received.length(); i++) {
      char c = received[i];
      if ((c < 32 || c > 126) && c != '\n' && c != '\r') {
        valid = false;
        break;
      }
    }

    if (!valid) {
      Serial.println("NONSENSE_RECEIVED");
      return;  // Descartar antes de actualizar RSSI
    }
    
    // Obtener RSSI
    int rssi = LoRa.packetRssi();  // RSSI de mensaje entrante
    sampleTotal -= rssiSamples[sampleIndex];    // Quitar T4
    rssiSamples[sampleIndex] = rssi;            // Guardar T0
    sampleTotal += rssiSamples[sampleIndex];    // Sumar al total

    sampleIndex = (sampleIndex + 1) % rssiSampleCount;    // Circular buffer
    if (sampleFilled < rssiSampleCount) sampleFilled++;

    int avgRssi = sampleTotal / sampleFilled;  // Promediar

    Serial.println("  RECV_ROVER_" + String(rssi) + "," + String(avgRssi) + "," + received);

    if (msgQueued && received.startsWith("ACK_")) {
      String ackFor = received.substring(4);
      if (ackFor == msgToSend) {
          msgQueued = false;
          msgToSend = "";

          if (ackFor == "SRA") LoRaShort();
          else if (ackFor == "MRA") LoRaMid();
          else if (ackFor == "LRA") LoRaLong();

          else if (receivingImage && ackFor.startsWith("REQ_")) lastChunkRequestTime = now;
      }
        
      if (ackFor.startsWith("CK")) {
        String lenCK = ackFor.substring(2);
        int newlen = lenCK.toInt();
        if (newlen > 0) expectedLength = newlen;
        Serial.println("  SET_CHUNK_SIZE_" + String(expectedLength));
        webSocket.broadcastTXT("CK_" + String(expectedLength));
      }

      else if (ackFor.startsWith("INT")) {
        String lenINT = ackFor.substring(3);
        float newInt = lenINT.toFloat();
        if (newInt > 0) csvInt = newInt;
        Serial.println("  SET_CSV_INTERVAL_" + String(csvInt));
        webSocket.broadcastTXT("CSVINT_" + String(csvInt));
      }

      else if (ackFor.startsWith("SET")) {
        String lenSTEP = ackFor.substring(3);
        int newStep = lenSTEP.toInt();
        if (newStep > 0) nemaStep = newStep;
        Serial.println("  SET_STEP_SIZE_" + String(nemaStep));
        webSocket.broadcastTXT("NEMA_" + String(nemaStep));
      }
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

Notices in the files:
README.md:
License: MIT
